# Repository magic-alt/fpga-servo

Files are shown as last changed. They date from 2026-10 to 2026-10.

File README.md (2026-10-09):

# fpga-servo

FPGA-based servo drive development platform for the ALINX AX7010 / Zynq-7000 board.

## Rev.A hardware target

`hardware/ax7010_servo_reva` is the first KiCad hardware baseline for a single-axis PMSM/BLDC servo inverter:

- 24-48 V DC bus, 10 A continuous phase current, 20 kHz PWM (confirmed 2026-10-09)
- three-phase bridge using 100 V N-channel MOSFETs
- FD6288T three-phase half-bridge gate driver
- three inline 5 mOhm phase shunts
- INA241A2 current-sense amplifiers, 20 V/V, 5 V supply, mid-supply reference
- ADS8588S 8-channel simultaneous 16-bit SAR ADC
- differential ABZ encoder input using AM26LV32E
- AX7010 40-pin PL expansion connector interface
- 2-layer PCB baseline, 2 oz copper recommended

The official recent AX7010 documentation names the two 40-pin PL expansion connectors J10/J11. Some older board revisions/silkscreens may differ; therefore the design uses neutral names `AX7010_PL_A` / `AX7010_PL_B` and documents the electrical pin map explicitly.

## Repository layout

- `hardware/` KiCad 10-native schematic / PCB baseline, BOM and design notes
- `fpga/` AX7010 XDC pin constraints matching the hardware pin map
- `docs/` architecture, calculations, bring-up and release gates
- `tools/` lightweight repository checks that do not require KiCad to be installed

## Status

Rev.A is a **development baseline**, not a fabrication release. Critical architecture, power-stage topology, interface allocation, footprint intent and layout zoning are present. Before fabrication the release gates in `docs/release_gates.md` must be closed, especially KiCad ERC/DRC, exact footprint verification, switching-loop review, thermal verification and connector revision confirmation.

Latest [layout-entry repair](docs/layout_entry_repair_2026-10-09.md): bootstrap diode polarity and ADC serial-mode straps are corrected; ERC and schematic/PCB parity are clean. PCB still has 271 DRC violations and 478 unconnected items; placement/routing freeze remains blocked. The [earlier schematic explanation and audit](docs/schematic_layout_entry_review_2026-10-09.md) retains passive simulation and remaining electrical/bench gates.

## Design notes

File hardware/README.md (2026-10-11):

# AX7010 Servo Drive Rev.A - KiCad baseline

**Current delivery scope (user revision, 2026-10-10): BOM and schematic only. PCB/layout repair is deferred. The working PCB retains earlier development edits and is not synchronized to the final bus-OCP schematic; the isolated unfinished routing candidate is not adopted. Do not use this board for fabrication or reuse historical zero-DRC/parity claims for the current schematic.**

## Files

- `ax7010_servo_reva.kicad_sch` - KiCad 10-native top-level schematic
- `power_input.kicad_sch`, `aux_power.kicad_sch`, `gate_inverter.kicad_sch`, `current_adc.kicad_sch`, `encoder.kicad_sch`, `ax7010_interface.kicad_sch`, `ocp_latch.kicad_sch` - native hierarchical child sheets
- `ax7010_servo_reva.kicad_sym` - versioned KiCad 10-native project symbol library
- `ax7010_servo_reva.kicad_pcb` - 2-layer PCB placement / critical-routing baseline
- `ax7010_servo_reva.kicad_pro` - KiCad project settings
- `bom.csv` - first-pass BOM and sourcing gates

`fp-lib-table` resolves `fpga-servo.pretty` through `${KIPRJMOD}`. `sym-lib-table` is versioned and resolves the project library through `${KIPRJMOD}`. The project therefore opens and passes ERC without a machine-specific global symbol table. `*.kicad_prl` and lock files remain local state.

The 2026-10-09 review fixed stale hierarchy instance roots, added seven FPGA-input pull-downs and six local IC bypass capacitors, repaired C43/C44/C45 (previously both terminals on GND), and synchronized the BOM and actual DNP flags. See `docs/schematic_review_2026-10-09.md` for evidence and remaining layout gates.

## Layout partitioning

From left to right in the PCB file:

1. AX7010 PL headers and signal interface
2. ADC + analog acquisition
3. gate driver / safety logic
4. six-MOSFET bridge + current shunts
5. motor and DC-bus terminal blocks

The auxiliary buck supply is kept along the top edge, away from the current-sense/ADC area.

## Current selection implementation (2026-10-10)

The eight-page native hierarchy retains three phase-inline INA240A1DR channels and 5 mΩ / 3 W two-terminal SMD shunts. Unused J2 is removed. Bus-only positive OCP uses a fourth INA240A1DR, a 2 mΩ / 3 W shunt and one LM393LV comparator at nominal +25 A. U16 and phase-window divider parts are removed. The hardware ARM latch and supervised clear remain.

The gate driver is non-inverting DRV8300DPWR with internal bootstrap diodes, 470 nF bootstrap capacitors and initial 33 Ω gate resistors. F1 is onboard Littelfuse 0456025.ER; no external fuse holder is required. J3.1 is VIN_RAW and F1 feeds VIN_FUSED. J6 remains an off-board PSU reference.

Important land decisions:

- RSH1..RSH4: local HoYLR2512_Kelvin two-terminal land; independent inner-side sense routing is required on all eight inputs.
- J4: KEFA KF950-9.5-3P; J1/J5: JILN 3210 family, finished holes 1.02 ±0.03 mm.
- L1: SOREDE 68 µH prototype selection; full 1 A regulator operation and inductor thermal rating remain unqualified. L2: Sunlord SWPA4020S2R2MT.
- NTC1/2: Shiheng CMFA103F3950 on a shared reviewed 0603 land. The onboard NTC2 does not establish actual remote motor temperature.

The [selection record](../docs/lcsc_sourcing_review_2026-10-10.md) and current native verification evidence supersede previous component counts and selection snapshots. BOM and procurement candidates are generated from the current hierarchy and sourcing evidence; stock observations are not reservations.

## Acceptance and limits

Run all repository checks, native ERC, fresh physical-pin netlist checks, all-severity PCB DRC with schematic parity, and the eight-branch Kelvin audit. Review every exported schematic page. A zero count does not establish electrical or thermal qualification.

See [release gates](../docs/release_gates.md). Gate A/B remain blocked pending measured switching, OCP delay/SOA, supply sequencing, current/thermal, connector and regeneration qualification. No fabrication approval is implied. Older implementation reports remain historical evidence; their external fuse, INA241, FD6288 and phase-window OCP descriptions do not describe this revision.

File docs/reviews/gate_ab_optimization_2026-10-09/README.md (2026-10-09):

# Gate A/B 验证流程优化 — 2026-10-09

基于远端 `feat/gate-ab-electrical-verification-20261009` 的 `389fbb5`；被测实现提交 `80512b5`。优化分支 `fix/gate-ab-evidence-integrity-20261009`。未修改硬件、FPGA、BOM 或库；原 main 工作区未提交配置和 history 保留。

## 修复与复核

- 清除预期波形后才执行模拟器；旧波形 + 空操作程序不再 PASS。
- 拒绝损坏、非有限值、时间倒序和覆盖不完整的波形。
- 缺失输入、畸形 XML、模拟器失败均输出 FAILED，覆盖旧资格 JSON。
- 网表脚本 ERC 明确 NOT_RUN；统一入口原生 ERC 报告才构成 ERC 证据，校验 metadata、完整层次 UUID、显式 violations 数组。
- 每次创建独立运行目录，保存源码前后哈希、产物哈希、工具版本、Git SHA/工作区状态、各步退出码和日志；CI 复用入口。
- 独立代码审查指出的畸形 XML/不完整 ERC 报告问题，均先通过 CLI 回归复现后修复，并通过复审。

## 本机新执行结果

macOS、Python 3.12.15、KiCad 10.0.3、ngspice 47。

| 验证 | 新结果 |
|---|---|
| 六项仓库检查 | 全部 PASS |
| 原生 ERC | 0 错误 / 0 警告 / 0 排除；4 类继承 ignored checks 如实保留，未改变规则 |
| 新原生板级网表 | 157 元件 / 166 网络 |
| 安全连接、PCB parity、PCB constraints | PASS |
| OCP 稳态数字回归 | 531 场景 PASS；不代表模拟链路响应验证 |
| Gate A/B 回归 | 18 项 PASS，无跳过；包含新鲜网表 mutation 和真实 ngspice |
| 入口失败隔离回归 | 2 项 PASS |
| PCB / 教程审计回归 | 11 / 4 项 PASS |
| 理想被动模型 | 回馈电容规律与 OCP RC 门限越过互检 PASS；无主动器件模型资格声明 |
| 源码哈希 | 各次运行前后精确一致 |
| 普通入口 | 自动证据 PASS，退出 0（提交前同一实现执行） |
| `--strict-gates` | 自动证据 PASS，Gate A/B BLOCKED，退出 2 |
| `--with-drc` | FAILED，退出 1；DRC 进程退出 -5，没有新 DRC 报告 |

DRC 日志：`Swift/SwiftNativeNSArray.swift:78: Fatal error: Array index out of range`。带 parity/refill 与最简原生命令均复现；根因尚未确定。未安装/升级工具或更改全局配置进行规避，未用历史 271/478 计数替代新执行结果。制造状态保持未放行。

## 证据

- [严格门禁 manifest](strict/manifest.json)、[本次 ERC](strict/erc.json)、[资格计算](strict/qualification.json)
- [Gate A/B 回归日志](strict/gate_ab_regressions.log)、[PCB 回归](strict/pcb_regressions.log)、[教程回归](strict/tutorial_regressions.log)
- [DRC 失败 manifest](drc/manifest.json)、[原生崩溃日志](drc/drc.log)

此目录保存精选原始报告，manifest 中保留完整运行全部产物的哈希。完整原始运行（含新导出网表与 SPICE 波形）分别位于隔离工作区的 `artifacts/gate-ab/20261009T153147Z-ys3wvk8b` 与 `artifacts/gate-ab/20261009T153206Z-k4xtcjo3`；可用 `python3.12 tools/run_gate_ab.py` 重新生成独立证据。入口失败隔离回归另用 `python3.12 -m unittest discover -s tools -p test_run_gate_ab.py -v` 执行。

Gate A/B 工程门禁仍 BLOCKED；主动器件动态模型、ADC 欠压许可、回馈策略、总关断时间及台架实测等清单见 [资格说明](../../gate_ab_verification_2026-10-09.md) 和 [release gates](../../release_gates.md)。远端 CI 尚未运行本地优化提交。

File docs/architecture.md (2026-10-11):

# Rev.A architecture

## Design intent

This board is a lab/engineering servo-drive daughter board for the ALINX AX7010. It deliberately keeps the hard real-time PWM, ADC timing and encoder counting in the Zynq PL while leaving high-power switching, signal conditioning and encoder line reception on the daughter board.

## Electrical target

| Item | Rev.A target |
|---|---:|
| DC bus | 24-48 V (confirmed 2026-10-09) |
| Operating bus maximum | 48 V; transient clamp/energy limit pending |
| MOSFET VDS | 100 V |
| PWM | 20 kHz |
| Continuous phase current | 10 A RMS (confirmed 2026-10-10) |
| Peak phase current | 20 A for 30 s (confirmed 2026-10-10); repetition interval pending |
| Maximum ambient | 40 degC (confirmed 2026-10-10) |
| Temperature-rise target | <=50 K; measurement locations pending; does not override lower component qualification limits |
| Cooling | Forced air (confirmed 2026-10-10); airflow and fan-fault behavior pending |
| Phase-current shunts | 5 mOhm, 3 W two-terminal SMD, independent Kelvin pickup; mounted thermal qualification open |
| Bus OCP shunt | 2 mOhm, independent Kelvin pickup; nominal positive +25 A trip only |
| Current gain | 20 V/V |
| Current transfer | 0.1 V/A |
| Current output zero | VA_5V / 2; nominal 2.55 V, requires per-channel calibration |
| ADC | 8 ch, simultaneous, 16 bit, 200 kSPS/ch |
| Encoder | 5 V ABZ (confirmed 2026-10-10); existing differential A+/A-, B+/B-, Z+/Z- interface; current/startup/common-mode envelope pending |
| Logic | 3.3 V |
| PCB | 2 layer, 1.6 mm, 2 oz recommended |

The latest user instruction removes the brake circuit from scope (2026-10-10). No board brake is added and PSU regeneration absorption is not assumed. S03 system surge/regeneration qualification remains OPEN; brake sizing is not a prerequisite for the other repair work. See the [thermal and encoder design brief](brake_thermal_design_basis_2026-10-10.md). The 20 A operating peak is distinct from the hardware OCP threshold and its fault overshoot; it is not yet demonstrated as an absolute current ceiling. U26 local free-air temperature must remain <=85 degC to use the current maximum-delay budget; 40 degC ambient permits only 45 K local rise there, pending thermal proof or a qualified redesign.

## Functional blocks

1. **DC-link / protection**
   - onboard F1: Littelfuse 0456025.ER, 25 A SMD, 72 VDC / 500 A interrupt rating; J3.1 enters VIN_RAW, F1 feeds VIN_FUSED; J6 alone is an excluded external system interface. No external fuse/holder
   - confirm actual bus current/inrush, source fault current <=500 A, bus surge/regeneration <=72 V, cable energy and fuse thermal coordination before higher-power operation
   - bulk capacitance close to bridge; D1 TVS is DNP, so no fitted TVS protection or qualified regeneration sink
   - bus-voltage divider to ADC

2. **Three-phase inverter**
   - six BSC040N10NS5 100 V MOSFETs
   - DRV8300DPWR non-inverted TSSOP20 driver; DI variant is not interchangeable
   - per-gate series resistor and gate-source pulldown
   - integrated bootstrap diodes; 470 nF CBOOT per high-side channel; external D2..D4 removed

3. **Phase-current measurement**
   - one 5 mOhm two-terminal SMD shunt in each motor phase
   - INA240A1 high-side/bidirectional amplifier per phase
   - REF1=VA_5V, REF2=GND -> nominal 2.55 V zero-current output
   - Kelvin sense traces, no load current in sense copper

4. **Data acquisition**
   - ADS8588S, 8 simultaneous channels
   - CH1/2/3: IU/IV/IW
   - CH4: VBUS
   - CH5: MOSFET-board NTC
   - CH6: board-mounted NTC2 (legacy net name NTC_MOTOR); no external motor sensor interface exists. S12 remains OPEN until the required sensing location/interface is confirmed.
   - CH7/8: unused, currently tied to GND
   - serial interface uses two DOUT lines; J2 is removed; only J1 connects the active AX7010 J10 signals
   - serial-mode DB0..6, DB9..13 and DB14/HBEN now visibly grounded; U6 uses the dedicated ADS8588S_SERIAL symbol

5. **Encoder**
   - AM26LV32E quad RS-422 receiver at 3.3 V
   - 120 ohm termination footprints on A/B/Z are currently DNP; fit decision depends on actual cable/encoder
   - shared VA_5V encoder supply through F2 PTC; exact PTC and short-circuit isolation remain unqualified

6. **Auxiliary power**
   - LM5164: DC bus -> 12 V gate/aux rail
   - TPS62901RPJR external-feedback 12 V -> nominal 5.1 V VA_5V rail; R94=75k/R95=10k, MODE=VIN (forced PWM 2.5MHz), VOS=output
   - 3.3 V logic is supplied by AX7010 VIO; there is no local 3.3 V LDO in the current schematic
   - safety AND gates and encoder receiver run from AX7010 `VIO_3V3`; ADC DVDD also uses this rail
   - dedicated digital isolation/buffer arrays are not fitted; partial-power behavior remains a qualification gate

## Safety state

All six non-inverted DRV8300DPWR PWM inputs are hardware-gated before the driver. `RUN_OK = GATE_EN & PWR_READY & ARMED`; any missing condition forces all six driver input commands low. FPGA deadtime remains at least 500 ns, with switching and shoot-through verification still required. CBOOT1..3=470 nF connect BST to each switch node; the driver has integrated bootstrap diodes. RG1..6=33 ohm and gate-source pulldowns=10 kohm require measured waveform validation.

The latest authorized hardware OCP detects **positive bus current only**, independently of the phase ADC. RSH4=2 mOhm separates VBUS_PROT from VBUS_BRIDGE, which supplies the high-side MOSFET drains. U5 INA240A1DR senses upstream minus downstream with both reference pins grounded, producing ideal 0.04 V/A for positive current. U15 LM393LVDDFR compares this output at pin 2 against R50=8.2k/R53=2k threshold at pin 3. At VA5=5.1 V, 1.0 V threshold gives nominal +25 A trip and pulls OCP_N low above threshold. U16/R51/R52 are removed. Reverse-current and phase-current window OCP are not provided.

The fresh passive calculation gives +24.357135..+25.659766 A using regulated VA5 bounds, divider +/-0.1% and shunt +/-1%. Adding selected-part TCR and published INA/comparator error terms expands the conditional static engineering estimate to +23.935464..+26.107636 A for +25..+125 degC component temperature and 24..48 V DC common-mode. This is not a permitted operating-temperature range or a guaranteed trip interval: supply test-condition applicability, grounded-reference errors, assembly/aging drift and dynamic effects remain open. See [the error budget and OEM limits](design_calculations.md). Bus current is not phase current, so this threshold is not an absolute ceiling for the 20 A phase operating peak. The FPGA diagnostic path remains available but does not replace hardware OCP.

Phase INA240A1 U2..U4 retain REF1=VA_5V and REF2=GND, nominal 2.55 V zero and 0.1 V/A sensitivity; R40..R42/C40..C42 serve the ADC only, with no OCP taps. ADS8588S straps remain `OS=000`, `PAR/SER=1`, `STBY=1`, `RANGE=0` (bipolar 5 V), `REFSEL=1`, and `DB15/BYTE_SEL=0`. Each phase and bus shunt's sense traces must reach the inner terminal lands independently of force copper.

## Grounding strategy

The PCB uses one continuous ground reference on the bottom layer. High-current bridge return paths stay local to the DC-link negative node and do not share narrow traces with ADC/encoder return currents. The analog section is physically isolated from switch nodes rather than separated with a slit plane.

## Configuration-time default and restart policy

R80..R85 pull the six raw PWM inputs to GND through 10k. R86 pulls GATE_EN to GND through 10k. With VIO valid and FPGA outputs high impedance, the AND gates have defined low commands and RUN_OK remains low. R56..R61 are separate pull-downs on the already gated driver inputs. C80..C83 bypass the four safety logic supplies; C84 bypasses bus INA240 U5 and C85 bypasses LM393LV U15. C43..C45 bypass INA240 supply pins to GND.

U20 implements hardware ARM latching, with supervised VIO/VA5 reset and raw OCP/PWR_GOOD asynchronous clear. Fault recovery alone cannot resume PWM. J1.10 FAULT_CLEAR re-arms on a rising edge with GATE_EN low. See `ocp_latch_review_2026-10-09.md` for the required clear protocol, timing conditions and bench gates. The bus detector has a nominal 1.000 V threshold (+25 A positive bus current). Response time, fault overshoot and complete error budget remain open.

U26 SN74LVC3G17 applies Schmitt conditioning to the open-drain supervisor reset, raw OCP_N and raw PWR_GOOD before ordinary CMOS logic. The conditioned PWR_READY feeds U11/U23; raw diagnostic nets and their original pull-ups remain intact.

U25 is now TPS389001DSER, independently powered by VIO and sensing VA5 through R92=3.24k/R93=1k. Undervoltage asynchronously clears ARM; recovery alone cannot re-arm. See [2026-10-10 repair](adc_undervoltage_repair_2026-10-10.md) for physical pin maps, static margins and open dynamic qualification. R92 uses the reviewed +/-0.702% static budget; the minimum falling threshold is 4.791889 V, maximum recovery 5.001931 V, and static VA5 range 5.026621..5.173923 V. These values do not qualify rapid droop or gate-off latency. ADC current-zero calibration and encoder supply acceptance must use the 5.1 V nominal rail.

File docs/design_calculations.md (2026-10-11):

# Rev.A design calculations

Current confirmed baseline: **24-48 V, 10 A RMS continuous phase current, 20 kHz PWM; 20 A peak for 30 s; 40 degC maximum ambient; <=50 K temperature rise; forced-air cooling; 5 V ABZ encoder; brake circuit cancelled by latest user instruction; PSU absorption not assumed** (2026-10-10). Peak repetition interval, airflow/fan failure, encoder maximum/startup current remain pending. See [thermal and encoder design basis](brake_thermal_design_basis_2026-10-10.md) and [current qualification record](layout_followup_qualification_2026-10-10.md); these inputs do not close release gates.

## Current sensing

For each phase:

- `Rshunt = 5 mOhm`
- `Gain = 20 V/V`
- `Vout_delta = Iphase * Rshunt * Gain`

Therefore:

`Vout_delta = Iphase * 0.005 * 20 = 0.1 * Iphase [V]`

With VA5=5.1 V nominal and reference=VA5/2=2.55 V:

| Phase current | Amplifier output |
|---:|---:|
| -20 A | ~0.55 V |
| -15 A | ~1.05 V |
| -10 A | ~1.55 V |
| 0 A | ~2.55 V |
| +10 A | ~3.55 V |
| +15 A | ~4.05 V |
| +20 A | ~4.55 V |

Software phase-current limits require calibration and dynamic validation. The approved phase peak is 20 A for 30 s. The latest authorized hardware OCP is a separate **positive bus-current** detector with nominal +25 A trip; U2..U4 remain phase ADC measurement channels and have no OCP comparator taps. Bus current and phase current are different quantities, so the difference between 20 A phase peak and 25 A bus trip is not a no-nuisance-trip margin.

RSH4=2 mOhm lies between `VBUS_PROT` (terminal 1, U5.IN+ pin 8) and `VBUS_BRIDGE` (terminal 2, U5.IN- pin 1). U5 is INA240A1DR, gain 20 V/V, with both reference pins grounded. Its ideal positive transfer is `Vout = Ibus * 0.002 * 20 = 0.04 * Ibus`. R50=8.2k from VA5 and R53=2k to GND set `Vthreshold = VA5 * 2/10.2`, giving 1.000 V at VA5=5.1 V and `Itrip=1/0.04=25 A`. U15 LM393LVDDFR compares U5.OUT at IN- pin 2 with threshold at IN+ pin 3; positive overcurrent pulls OCP_N low. U15's unused comparator has IN+ pin 5 at GND, IN- pin 6 at threshold, and output pin 7 NC. U16/R51/R52 are removed. This circuit provides **no reverse-current OCP** and no phase-current window protection.

The fresh candidate XML (2026-10-10), `check_adc_validity.py` and `corner_current_limits()` give VA5=5.026621..5.173923 V. Combining this rail range, R50/R53 initial tolerance +/-0.1%, and RSH4 +/-1% yields **positive passive-only trip +24.357135..+25.659766 A**. This excludes divider/shunt temperature and lifetime drift, INA gain/offset/output swing and PWM common-mode recovery, LM393LV offset/overdrive/propagation, ripple, pull-up/logic/gate delay and fault-current overshoot. It is not a guaranteed trip interval or maximum fault current. The grounded-reference INA output near zero and negative current also requires bench characterization; no negative-current transfer or protection is claimed.

The [versioned static-budget evidence](sourcing/bus_ocp_static_budget_2026-10-10.json) records the native XML hash, OEM sources and limits. The extended static engineering budget in `bus_static_error_budget()` gives **+23.935464..+26.107636 A**, while preserving nominal +25 A. Its conditional calculation envelope is local component temperatures +25..+125 degC and DC bus common-mode 24..48 V; this is not permission to exceed the board's 90 degC hotspot target or another component's lower limit. The shunt OEM only specifies its TCR test over +25..+125 degC, so no cold-temperature bound is claimed.

| Term | Maximum/allocated magnitude used |
|---|---:|
| R50 PTFR0603B8K20P9 | Initial 0.1% + 25 ppm/degC × 105 K = 0.3625% |
| R53 TD03G2001BT | Initial 0.1% + 25 ppm/degC × 105 K = 0.3625% |
| RSH4 HoYLR2512-3W-2mR-1% | Initial 1% + 50 ppm/degC × 100 K = 1.5% |
| INA240 gain | 0.2% + 2.5 ppm/degC × 100 K = 0.225% |
| INA240 input offset | 25 uV + 250 nV/degC × 100 K, plus DC CMRR and PSRR = 87.739 uV |
| LM393LV input offset | Full-temperature 3 mV, plus DC CMRR and PSRR = 4.155 mV |

The [RESI PTFR ordering table](https://atta.szlcsc.com/upload/public/pdf/source/20250401/FF0B2EF5B31106388F28E532ECCD4B84.pdf) identifies code P as 25 ppm/degC; the [FH TD ordering table](https://atta.szlcsc.com/upload/public/pdf/source/20200616/C657321_2CFA27FA726BC0D0F6223AF922169515.pdf) identifies G as 25 ppm/degC. A conservative 105 K resistor span covers a +20 degC reference to +125 degC. [HoYLR's exact 2mOhm approval sheet](https://atta.szlcsc.com/upload/public/pdf/source/20260807/2744A3B9486B05923CE3C700940B3DAC.pdf) specifies 50 ppm/degC. These initial-plus-TCR bounds do not include mounting or qualification-test drift.

The [INA240 electrical table](https://www.ti.com/lit/ds/symlink/ina240.pdf) supplies gain/offset limits and drift, minimum DC CMRR 120 dB and maximum PSRR 10 uV/V. The model allows common-mode change from the 12 V test point to 48 V and actual supply deviation from 5 V. The [LM393LV table](https://www.ti.com/lit/ds/symlink/lm393lv.pdf) supplies full-temperature +/-3 mV offset, 60 dB CMRR and 70 dB PSRR; drift is not added again. A 1.1 V comparator common-mode envelope bounds the threshold crossing.

The equation is `Itrip = ((Vthreshold + VOS_comparator) / G_actual - VOS_INA) / Rshunt_actual`, sweeping independent worst signs and both verified VA5 bounds. This remains **an engineering estimate, not a guaranteed trip interval**: LM393LV's quoted error-table conditions are at/up to 5 V, while actual VA5 is slightly higher; INA reference rejection and input-bias mismatch lack guaranteed maxima for this application. Grounded-reference transfer, Kelvin/thermoelectric errors, reflow, load-life/humidity drift, PWM transients and dynamic fault overshoot still need qualification. The OEM shunt's separate reliability-test allowances cannot be treated as zero drift or collapsed into a lifetime guarantee. The model checks the three exact MPNs before using their TCRs; an alternate needs its own reviewed budget.

RSH4 dissipates 1.25 W at a constant 25 A and 0.8 W at a constant 20 A. Its bus RMS current, pulse energy, mounted temperature and independent inner-land Kelvin pickups require separate qualification; phase RMS current cannot be substituted for bus RMS current.

Shunt dissipation is `P = I_RMS^2 * R`:

| RMS current | Shunt dissipation |
|---:|---:|
| 10 A | 0.50 W |
| 15 A | 1.125 W |
| 20 A | 2.00 W |
| 25 A | 3.125 W |

Select HoYLR2512-3W-5mR-1% (3 W, two-terminal SMD). Apply independent inner-land Kelvin pickup and verify its derating and assembled temperature. A 3920 >=5 W alternative is the fallback if the 2512 assembly cannot meet the thermal limit.

At the confirmed 10 A RMS, each nominal shunt dissipates 0.5 W. A phase held at the 20 A magnitude bound dissipates 2 W; for 30 s this is 60 J per shunt, before resistance tolerance and temperature drift. A sinusoidal phase with 20 A instantaneous amplitude has a different RMS loss; use the 2 W value as a conservative per-shunt upper envelope until the actual peak waveform is specified. With baseline 10 A RMS and a conservative 20 A flat-current interval occupying fraction d, the illustrative average is `Pshunt=0.5+1.5d W`; for a start-to-start repetition period Trep, `d=30/Trep` with Trep>=30 s. No repetition period is assumed.

At 40 degC ambient, the general 50 K rise target corresponds to a 90 degC measured hotspot limit, subject to every component's lower qualified limit. A 50 K rise implies an effective shunt-to-ambient thermal resistance <=100 K/W at steady 0.5 W, or <=25 K/W at steady 2 W; these are assembly targets, not package ratings. For a first 30 s pulse from an established 10 A RMS thermal state, an illustrative linear thermal model requires `0.5*Rtheta_steady + 1.5*Ztheta(30s) <=50 K`; repeated pulses require accumulation, hot resistance and airflow validation. The shunt's nominal 3 W rating does not prove this condition. U26's current maximum-delay qualification is limited to 85 degC local free-air temperature, hence <=45 K local rise at the confirmed ambient. Forced air requires minimum airflow, blockage/fan-loss handling and assembled-board soak evidence.

## ADC resolution

The ADS8588S is configured for ±5 V input range. The nominal LSB is:

`10 V / 65536 = 152.6 uV/LSB`

Since current sensitivity is `0.1 V/A`, the ideal code resolution is:

`152.6 uV / 0.1 V/A = 1.526 mA/LSB`

Noise, PWM common-mode transients, reference error and layout dominate before quantization does.

## Bus-voltage divider

Rev.A nominal divider:

- high side: 280 k + 280 k
- low side: 39 k
- total: 599 k

`Vadc = Vbus * 39 / 599 = 0.065108 * Vbus`

| VBUS | ADC voltage |
|---:|---:|
| 24 V | 1.563 V |
| 48 V | 3.125 V |
| 55 V | 3.581 V |
| 60 V | 3.906 V |
| 75 V | 4.883 V |

The board is not specified for 75 V continuous operation; this table only shows divider headroom.

The operating range is 24-48 V; every table row above 48 V is calculation-only. C5=10nF and `(560k || 39k)` give tau=364.608us and fc=436.51Hz. This bus-monitor filter cannot be treated as fast hardware overvoltage protection.

## MOSFET conduction sanity check

For one current path through two BSC040N10NS5 devices, using 4 mOhm each at the datasheet test condition:

`Ppath ~= I^2 * 8 mOhm`

- 10 A -> 0.8 W instantaneous conduction path loss
- 15 A -> 1.8 W (historical comparison)
- 20 A -> 3.2 W
- 25 A -> 5.0 W

Actual inverter dissipation must be computed over PWM duty, device temperature, switching energy and dead-time diode conduction. These values are only a first-order check.

## Gate-drive current sanity check

U1 is the non-inverted **DRV8300DPWR**, with integrated bootstrap diodes. The DI variant is not interchangeable with the hardware all-low inhibit. D2..D4 are removed; CBOOT1..3 are 470 nF between BST and the corresponding switch node, and RG1..6 are 33 ohm. See the [TI DRV8300 datasheet](https://www.ti.com/lit/ds/symlink/drv8300.pdf) for the D/DI input distinction and PW20 pin map. All six input commands are gated; FPGA deadtime remains at least 500 ns, pending measured switching verification.

Using BSC040N10NS5 Qg=72 nC as an illustrative charge and the driver's typical 0.75 A source/1.5 A sink capabilities gives Q/I=96 ns/48 ns. These are ratios, not guaranteed switching or fault turn-off times: 33 ohm resistance, Miller charge, gate voltage, driver impedance and board inductance dominate actual waveforms. One 72 nC charge from a nominal 470 nF bootstrap capacitor gives an ideal 0.153 V droop before effective-capacitance derating, quiescent/leakage charge, duty-cycle hold time and recharge losses. Bootstrap refresh, UVLO, effective capacitance and full shutdown latency remain unqualified.

## Onboard input fuse

F1 is **Littelfuse 0456025.ER**, a 25 A very-fast-acting SMD fuse on the PCB. J3.1 and F1.1 are VIN_RAW; F1.2, Q7 drain and the U18 LM74502 reverse-polarity controller input are VIN_FUSED. The LM5164 auxiliary regulator is supplied from VBUS_PROT, downstream of reverse-polarity protection. J6 is only the excluded external system interface; no external fuse or holder is required by this design revision.

The [Littelfuse 456 datasheet](https://www.littelfuse.com/assetdocs/littelfuse_fuse_456_datasheet.pdf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) specifies the **25 A row** at 500 A interrupting capacity at 72 VDC, and 1000 A at 32 VDC. Its 125 VAC label does not establish a 125 VDC rating. The 72 VDC rating exceeds the 48 V operating maximum; regeneration/surge bus voltage <=72 V and prospective source fault current <=500 A remain open qualification requirements for this prototype selection. Catalog stock is not electrical qualification.

Nominal cold resistance is 1.92 mOhm and nominal melting I²t is 45 A²s; neither alone proves fault coordination. Manufacturer time-current, continuous-current/ambient derating, inrush, source/cable energy and mounted-temperature limits must be met. OEM thermal conditions use broad 100 um copper; the present two-layer copper/via implementation does not independently prove 25 A operation. F1 does not replace fast bus OCP or limit fault current to 25 A. This is a documented critical single-source prototype exception.

## VA5 validity and R92 tolerance

U25 TPS389001DSER senses VA5 through R92=3.24k/R93=1k while powered independently by VIO. R92's selected 0.1%, 25 ppm/C primary and reviewed alternative use a common +/-0.702% static budget; R93/R94/R95 use +/-0.25% including their stated allocations. These are prototype budgets derived from separate qualification tests/allocations, not a combined-environment or lifetime guarantee.

`check_adc_validity.py` calculates falling shutdown threshold 4.791889..4.961002 V, maximum recovery 5.001931 V, and regulated VA5 5.026621..5.173923 V. The minimum falling threshold is 41.889 mV above ADS8588S's 4.75 V minimum. The allocated 10 mV normal ripple still leaves static recovery headroom. This does not qualify fast droop: TPS3890's 18 us typical delay at 5% overdrive is not a guaranteed maximum, and the complete supervisor-to-MOSFET shutdown chain remains open.

## Two-layer current routing

The high-current path must not rely on a single narrow trace. Plan wide top-layer copper, bottom reinforcement and qualified stitching near terminals/MOSFETs/shunts. The prior routed PCB is a development baseline; SMD-shunt integration requires fresh routing, DRC and thermal review. Verify temperature rise on the actual stack-up and copper weight.

## Local passive simulation (2026-10-10)

`tools/simulate_layout_entry.py` extracts actual passive values and checks their physical-pin topology in a fresh KiCad XML netlist before emitting six ngspice decks, CSV waveforms, JSON results and a plot. This is not a complete inverter/device simulation.

- R40/C40: tau=47ns, fc=3.386MHz; 20kHz attenuation is only -0.0001515dB. The filter does not remove PWM ripple and serves only the phase ADC. Its ideal 2.5-to-4.9 V step crosses the 3.7 V midpoint at about 1.03358 us for a step beginning at 1.001 us; this is phase ADC settling, not bus OCP delay.
- R88/C92: tau=1us with an ideal FPGA output. No Schmitt threshold, propagation, metastability or power-ramp model is included.
- C1+C2=200uF nominal: an unsunk ideal 1A regeneration current raises 48V to 55V in 1.4ms, storing only 0.0721J extra. 55V is an overvoltage example, not an operating allowance.
- Three 5mOhm shunts at 10A RMS dissipate 0.5W each, 1.5W total. Package rating alone does not qualify assembly temperature.

Full current/thermal/switching qualification remains open; see [power-stage review](power_stage_layout_review_2026-10-09.md) and [analog/safety review](analog_safety_layout_review_2026-10-09.md).

## Kelvin electrical-node modeling

The selected two-terminal SMD shunt has one physical terminal per side. Independent sense and force traces meet within that terminal land and share its electrical node:

- U phase: `SW_U` and `PH_U`
- V phase: `SW_V` and `PH_V`
- W phase: `SW_W` and `PH_W`
- Bus: `VBUS_PROT` and `VBUS_BRIDGE`

Kelvin behavior is enforced in PCB routing: each INA240 input trace must originate independently at the inner edge of the corresponding two-terminal SMD shunt pad. Force and sense copper may meet only within that terminal land. A two-terminal shunt must not be represented by invented physical sense pins or jumper groups. PCB integration and thermal qualification are separate gates.

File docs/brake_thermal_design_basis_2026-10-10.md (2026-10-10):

# 20A / 30秒、40°C风冷与编码器供电设计依据

## 当前确定的输入

用户确认：24..48V母线、20kHz PWM、10Arms连续相电流、20A峰值持续30秒、最高环境40°C、允许温升50K、风冷、5V ABZ编码器；用户最新指令取消制动电路；不将板载制动列为待实现任务，不假定电源具有回馈吸收能力。20A重复周期尚未给出，不采用历史25A/5秒。不得把20A相电流转换为20A母线回馈电流。

本文件保留热设计和编码器供电候选依据。制动候选方案已按用户最新指令撤销。当前原理图没有制动支路；D1仍DNP，U18 OV仍接地。S03/S05/S08/S11和动态资格仍OPEN。

## 热设计与布局限制

10Arms时，每只5mΩ分流器名义0.5W；20A幅值持续30秒的保守平顶包络为2W和60J/只。三只各自使用该上界有利于保守热设计，并不意味着平衡三相能同时以同向20A运行。实际波形、峰值重复周期及热阻抗决定真实损耗和热累积。

从10Arms热稳态切换到上述峰值包络，线性近似为`ΔT(30s)=0.5Rθ+1.5Zθ(30s)`；要求测量点不超过50K温升，需计入热态阻值、器件/铜/端子互热与风量。重复周期T从一次峰值开始到下一次开始计算，`d=30/T`，名义平均每只分流器`P=0.5+1.5d W`；未知T时不得给出平均损耗合格结论。

40°C+50K得到一般测量点90°C限值，但不能套用到具有更低资格温度的部件，也不能把外壳/板温当结温。U26 SN74LVC3G17 Rev.F §6.6最大延时表只覆盖TA=-40..85°C；该芯片推荐工作温度到125°C并不扩大延时表。沿用原32ns数字链预算时，应把U26放在远离MOSFET、分流器和磁件的冷区，证明局部自由空气温度<=85°C（40°C环境下局部温升<=45K），并满足输出负载条件。若不能保证，则需要替换有相应高温最大时序保证的逻辑并重新建立延时预算，不按典型曲线外推。

风冷验收需要最小风量/流向、堵塞及风扇故障处理；PCB散热铜、风道、外壳和安装状态必须与热试验一致。30秒是长脉冲，不能只用MOSFET纳秒/微秒SOA图或分流器5W名义额定放行。

## 5V ABZ默认兼容合同候选

现有接口是差分RS-422 A+/A−、B+/B−、Z+/Z−，不是所有“ABZ”电气输出都通用。建议默认限定为允许4.5..5.5V供电的5V差分型号，预留**300mA连续供电设计额度**；这是一项待电源和短路资格验证的工程预算，不是工业ABZ统一额定或现板已保证的输出能力。

例：SICK VFS60系列官方2013年产品资料的4.5..5.5V TTL/RS422档列出无负载工作电流40mA、输出负载电流30mA；按`40mA+3×30mA=130mA`可作量级叠加参考。该历史系列资料不能替代当前准确采购型号的最大输入电流保证，也不代表用户已选定该编码器。300mA设计额度不涵盖未知上电浪涌、线缆充电及所有其他型号。最终选用型号必须满足明确的持续/启动电流、供电窗口、共模和频率合同。

当前VA5静态5.026621..5.173923V符合上述候选编码器窗口的电源端范围，但F2、线缆、连接器压降和动态下陷未计入。仅静态在300mA下，从最低VA5到4.5V可分配总串联电阻约1.755Ω；此数值未留瞬态/纹波裕量，不能直接作为布线允许值。F2的0.5A文字不是热态保持电流保证，PTC也不是快速精密限流器。

编码器当前与ADC/OCP共用VA5。需比较两种方案：带反灌/短路资格的限流支路，或由12V产生独立编码器5V再限流。独立支路降低直接拖垮VA5的耦合，但12V总负载和启动仍需核算。未确定负载/启动与器件之前，不将F2占位符视为已修复，也不任意添加一个普通PTC关闭S08/S11。

## 制动范围变更

用户已明确不需要制动电路，本轮不新增制动支路，也不以制动参数未提供阻止其他修复。S03仍仅记录尚未验证的系统浪涌/回馈工况；取消电路不构成该系统资格的通过证据。

## 原厂依据与后续证据

- [TI SN74LVC3G17 Rev.F](https://www.ti.com/lit/ds/symlink/sn74lvc3g17.pdf)：§6.3工作温度与§6.6时序表应分开使用。
- [SICK VFS60系列官方产品资料](https://www.sick.com/media/docs/8/28/628/product_information_vfs60_motor_feedback_system_rotary_incremental_en_im0022628.pdf)：2013年版第4页5V差分档预算实例；不作为当前采购或通用编码器承诺。另核查的DFS60B-BACA02048具体型号实际为10..32V，不能因系列通用图出现5V就当成5V型号。
- [Ohmite 650FPR005E](https://www.ohmite.com/catalog/60-series/650FPR005E/)：5W、1%、100ppm/°C；完整温度/寿命/装配资格仍需补齐。
- [TI LM74502](https://www.ti.com/product/LM74502)：反接保护不包含反向电流阻断。

以上是热设计输入、计算及编码器候选供电合同，没有新增实体波形或热浸证据。PCB候选的原生DRC结果另见[铜线修复记录](pcb_legacy_route_repair_2026-10-10.md)。

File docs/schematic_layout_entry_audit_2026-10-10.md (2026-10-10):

# AX7010 Servo Rev.A 原理图及 PCB layout 准入审计报告

审计日期：2026-10-10。审计方式：只读设计审核、新鲜原生导出、物理网表追踪、厂商资料复核及逐页图面检查。

## 1. 放行结论

**正式布局布线：BLOCKED。当前不能称为“原理正确无误、可直接进入正式 PCB layout”。**

原生连接及结构检查已经通过，许多旧接线缺陷确已修复。但是 ADC 欠压许可存在确定缺口；相 shunt 不覆盖内部桥臂直通；回馈/浪涌、功率额定边界、关键选型及若干接口功能仍未闭合。这些项目可能改变电路拓扑、器件数量或机械空间，应先于正式相关区域布线处理。

| 阶段 | 决定 | 条件与边界 |
|---|---|---|
| 机械及功能分区、可撤销摆件研究 | PARTIAL，可开展 | 标明保护/电源/接口未冻结区域，保留新增检测、制动、连接器和测试点空间；不能作为终版布线依据 |
| 以当前电路为冻结输入开展正式布局布线 | BLOCKED | 关闭本报告列为“正式layout前”的设计决定；按区域放行必须明确该区域无未决拓扑/关键封装依赖 |
| 布局/布线冻结 | BLOCKED | 除上述项，还须完成动态设计界限、关键封装/接口/规则审核和PCB闭环 |
| 投板、功率上电、量产资格 | BLOCKED | 当前PCB有真实短路、478未连接；制造、低能量验证及热/保护实测均不能由本报告替代 |

台架波形需要样机，**不把尚无样机的全部实测项目一概要求在首次布局前完成**。但保护架构、可计算的额定界限、准确封装和接口必须先有明确设计输入。Gate B保持开放并不禁止受控样机设计；它禁止宣称功率保护/制造资格已经完成。

本报告的PASS仅覆盖明确列出的检查。未取得器件动态保证、真实负载或实测证据的项目，分别列为资格缺口；不把缺少证据写成“已证实一定失效”。

## 2. 实际审计基线

| 项目 | 本次值 |
|---|---|
| 源提交 | `58ddc5e29ff316f34002cf973014cde1fd32f42d` |
| 审计分支 | `audit/schematic-layout-entry-20261010`；从最新main同一提交创建，未提交、未推送 |
| 源文件 | KiCad 10原生顶层＋七子页；旧.sch/.lib不作为源 |
| 工作区 | `.kicad_pro`已有232行本地新增设置，纳入实际ERC/DRC基线；原本未跟踪的教程产物和hardware/.history不动 |
| 工具 | KiCad CLI/pcbnew 10.0.3；本机Python 3.13.9；ngspice-46共享DLL。仓库推荐3.12，本轮未验证3.12 |
| 规格 | 24..48V、20kHz、10A连续相电流；10Arms为暂定计算解释，峰值/环境/散热/回馈包络未冻结 |
| 系统原生XML | 159对象 / 167网络 / 648物理引脚节点，包括板外F1/J6 |
| 板级原生网表 | 157元件 / 166网络；PCB161封装=157电气＋H1..4机械 |
| 装配属性 | DNP：D1、R32、RT1..3；板外：F1/J6。J2实际不是DNP |
| BOM | 159行，值/封装/MPN字段与新网表无差异；120对象MPN为TBD |

原始证据目录：[artifacts/schematic-audit/20261010](../artifacts/schematic-audit/20261010/)。`manifest.json`保存检查命令、退出码及源哈希；`analysis.json`保存派生统计。648引脚附表是连接追踪底稿，**不等于648个引脚均完成独立厂商应用资格认证**。

## 3. 新鲜检查结果及限制

| 检查 | 本次结果 | 说明 |
|---|---|---|
| XML、板级网表、独立BOM、完整PDF导出 | exit 0 | 均从当前原生层次生成；未运行会覆盖hardware/bom.csv的旧导出脚本 |
| 原生ERC | exit 0；8页，0错误/0警告/0排除 | 报告包含error/warning/exclusion；继承4类ignored_checks，见下表 |
| 六项源检查 | 全部exit 0 | native_schematic、kicad_grid、schematic_layout、schematic_connectivity、power_wiring、design |
| 安全网表 | exit 0 | 157元件/166网，逐物理脚关键连接回归 |
| OCP稳态行为 | exit 0，531场景 | 不含亚稳、模拟延迟、斜坡、脉宽或真实开关模型 |
| 逐焊盘PCB parity/约束 | 均exit 0 | 元件/焊盘/网络一致，不能证明现有铜无短路 |
| PCB检查器回归 | 11项通过 | 真实错误网、缺器件/焊盘等回归 |
| 教程静态检查器回归 | 4项通过 | 工具本身仍有off-board误报，S17 |
| 统一入口回归 | 2项，1通过/1跳过 | 跳过要求ngspice CLI及POSIX可执行脚本的用例 |
| Gate A/B回归 | 18项，16通过/2跳过 | 使用本轮XML执行物理网表mutation；跳过ngspice CLI及POSIX相关用例 |
| Gate A/B资格检查 | exit 2，A/B均BLOCKED | 物理合同通过；严格门禁未关闭。低层qualification.json的ERC=NOT_RUN指该工具不执行ERC，本次ERC以erc.json为准 |
| 被动/理想源仿真 | exit 0；6个deck，解析交叉验证通过 | 使用本机ngspice DLL；缺spinit提示保留。无厂商有源器件/开关/热模型，不能替代被跳过的CLI测试 |
| 教程辅助静态parity | exit 2 | F1/J6板外属性误报，已解释但未修改/隐藏原始结果 |
| 原生DRC | exit 5 | 271违规=220错误/51警告；478未连接；0原生schematic parity问题；未保存PCB |
| 源文件完整性 | 前后SHA256完全一致 | 最终交付另复核；不读取环境变量值或.env |

**继承忽略类型**（不是本次新增，未降低任何严重级别）：

| 报告 | ignored_checks |
|---|---|
| ERC | single_global_label、four_way_junction、simulation_model_issue、footprint_filter |
| DRC | missing_courtyard、track_not_centered_on_via、tuning_profile_track_geometries、footprint_filters_mismatch、footprint_type_mismatch |

零exclusion不等于零ignored。项目脚本检查T分支/层次连接不能替代全部原生ERC类别；封装过滤器、类型和庭院仍须独立审阅。单次使用的全局标签检查被忽略；仿真模型问题检查被忽略也不能证明模型合格。

DRC按类型：间距113、阻焊桥88、孤立铜43、跨网短路17、悬空走线8、走线交叉2。当前20条历史走线、0过孔、5个zone，实际板网180个；其中旧网名不能当成仍有效的原理图网络。上述数量来自本轮报告，不抄用2026-10-09历史记录。

## 4. 逐功能/逐页审查

### 4.1 系统、电源输入和母线（第1、2页）

新图及网表确认：外置电源J6正极→F1→VIN_FUSED→J3.1→Q7/U18；J3.2为GND。Q7/Q8共源背靠背：Q7.5在输入，Q8.5在VBUS_PROT，U18.8接公共源，.6接门极，.4电荷泵电容返回VS。U18的NC3保持NC，OV7接地是明确禁用OV，不是漏接。[LM74502原厂手册][D3]的脚序及基本应用相符。

D1 K1/A2与图/封装一致，但实际DNP；不以TVS图形存在认定已有钳位。C1/C2各100uF，48V标称储能0.2304J。母线分压R1/R2=280k＋280k，R3=39k：24/48V分别1.5626/3.1252V；C5=10nF，时间常数364.608us，截止436.51Hz。这是慢监测，不能充当快速硬件OV保护。高侧两只电阻分担电压，但准确耐压/温漂尚待选型。

Q7/Q8标称每只4mΩ只适用于厂家相应VGS/温度测试条件。假设母线电流10A时两管导通损耗约0.8W，仅为示例；相电流10Arms并不能推出母线电流10A。浪涌、回馈、保险配合及散热分别按S03/S05/S21处理。

### 4.2 AX7010接口（第3页）

采用官方公开V2原理图第5/15页及官方手册J10表交叉复核。公开图纸标题栏日期2018-10-08，厂商仓库名2023.1表示教程/工具版本，不能冒充2022实板测量。新下载原厂PDF哈希与历史缓存一致：`e35eb1b654774a6f314de0140f5608d38a1c6be72d1c3e1008f5e288ac83c87e`。

J1.1/.37/.38为GND，.2保持NC，.39/.40为3.3V；37/38的地符号在厂商图中旋转绘制，已放大确认，不应误读成IO。J1.3..8六PWM、.9 EN、.10 CLEAR、.11..18 ADC、.19..21 ABZ、.23 OCP、.24 PGOOD与现行XDC及厂商活跃脚映射相符。R80..86七个10k真实连接六PWM与EN，配置期偏置存在。

J1.22以及辅助/备用信号为真实NC；XDC中的ENC_FAULT_N/AUX/SPARE预留并不实现这些接口。J2当前只有电源/地连接，信号NC；图面“DNP”与真实属性不一致见S15。线缆方向、回流、电源预算和实际FPGA工程仍按S10验证。

### 4.3 辅助电源（第4页）

U12 LM5164的VIN/EN接VBUS_PROT，GND/EP接GND，BST电容跨BST/SW，68uH接SW到12V；R20=100k，反馈453k/49.9k，Type-3 ripple网络453k/3.3nF/56pF关系与原厂示例相符。1.2V反馈基准下理想电阻比为12.0938V，实际COT纹波注入与误差会改变稳态值，不能据此报成已测输出。按12V/300kHz/68uH理想CCM计算，24/48V时纹波约0.294/0.441App；1A负载时峰值约1.147/1.221A。44uF名义输出电容只给约2.79/4.18mV纯电容纹波，不含偏压/ESR/瞬态。[D8]

L1真实料号为Coilcraft MSS1246T-683MLC，25°C表中饱和/温升电流不能直接搬到高温；L2真实料号74438356022，原厂新手册003.002/2026-09-01有电流及PCB热测试条件。未发现“2.2uH显然不足以支撑1A”的证据；仍须按电感容差、热与芯片限流上界计算。[D14][D15]

U13 TPS62163DSGR是固定5V型号；.5 FB→AGND，.6 VOS→5V，.1/.4/.9接GND，.7→L2，.8为PG。不是应补分压的可调TPS62160。输入12V在推荐3..17V内；2.2uH＋22uF属于厂商常见应用组合。两buck开漏PG并接并由VIO拉高，其高阻/失电行为与共享编码器负载见S08/S09。[D9]

### 4.4 电流采样、ADC及OCP（第5页）

U2..4：pin8 IN+接对应SW，pin1 IN−接PH，pin6供电；pin7 REF1接VA5、pin3 REF2接GND，pin2及必须接地的保留pin4均接地。C43..45已正确跨供电/GND，不再是两端落地。A2增益20、5mΩ shunt得到0.1V/A，零位跟随VA5/2；±10A在5V标称时输出1.5/3.5V，±25A触理想电源轨不能当作保证量程。[D4]

U6串行模式所需pin16..22/27..33均接地，不再沿用13脚NC旧错误；OS=000、PAR/SER高、STBY高、RANGE低、REFSEL高。四AVDD去耦、DVDD去耦、两独立REGCAP电容和REFCAPA/B短接去耦关系正确。三个测流输入为49/51/53，母线55，两个温度57/59，未使用模拟通道及负输入接地；BUSY/DOUT/RESET等与J1对应。[D2]

U15高限比较器是IN−接测流、IN+接高参考，过高拉低；U16低限是IN+接测流、IN−接低参考，过低拉低，六个开漏输出并入OCP_N并经4.7k拉到VIO。未用第四比较器两输入接GND、输出NC，不参与OCP。名义参考高/低4.705882/0.294118V，名义阈值±22.0588A。仅VA5±5%、阈值电阻±0.1%、shunt±1%时约20.743..23.402A；还未计入IC、温度、动态。[D5]

47Ω/1nF的3.386MHz网络不是完整20kHz抗混叠滤波；ADC和OCP共用节点，不能为美化采样单独加大C而不重算保护。ADC±5V量程的理想电流码宽约1.526mA/LSB，不等于实际测流精度。S01/S04/S12/S20仍开放。

### 4.5 门驱动及逆变桥（第6页）

FD6288T按原厂V1.6 p6核对20脚：1..3 HIN、4..6 LIN、7供电、8 COM，9/10/11对应W/V/U低侧，12/15/18对应W/V/U VS，13/16/19对应HO，14/17/20对应VB。新网表与此对应；六MOS的S1..3/G4/D5及高低桥臂连接正确。六10Ω栅阻及10k栅源电阻有真实局部回路。[D6][D7]

D2..4阴极pad1接BST、阳极pad2接12V，CBOOT跨BST/SW，极性旧缺陷未复现。名义1uF按Qg72nC算一次充电降压0.072V，仅是单项示例；**持续高侧导通还必须包含VGS/10k的栅源电阻负载**，以及静态耗流、漏电和有效容量。驱动内部互锁/死区确实存在，不能误写成“FD6288没有互锁”；也不能据此宣称所有MOS短路故障受到保护。S02/S04/S07为本区域关键门禁。

四端shunt的force1/2和sense3/4左右对应关系正确、同侧同网是有意建模；Kelvin不能由网名区分保证，必须让感测走线独立从3/4焊盘引出，不共享负载铜。

### 4.6 编码器（第7页）

U7 AM26LV32E的三对输入、输出和使能脚均与厂商图对应，VCC=VIO；输出电平属于FPGA同域，但尚未证明线缆输入及部分供电行为。U19已是正确RVZ14脚映射，不再使用旧错误封装；NC1/2/3/4/6/7无须为ERC强接，5/10接GND，六IO接A/B/Z正负。[D10][D11]

RT1..3确为DNP，不是默认已端接；J5.9 SHIELD确为NC，不是已有屏蔽回路；F2仅值“0.5A PTC”不代表硬限流。尤其要区分接收器-7..7V共模能力与U19 0..5.5V工作范围，见S11。

### 4.7 硬件锁存和复位（第8页）

U20 pin1 CLK来自CLEAR→1k/1nF→U21 Schmitt，pin2 D来自反相GATE_EN，pin6 /CLR来自U23健康组合，pin7 /PRE拉高，pin5 Q=ARMED；/Q未使用。U23组合OCP_OK、PWR_READY和POR_OK；U11组合EN、PWR_READY、ARMED。U24检测VIO、U25由VIO供电检测VA5，CT悬空是12..28ms恢复延时选择，不是遗漏电容。[D1][D12]

稳态逻辑满足：故障清除Q；单纯故障恢复不恢复Q；新CLEAR上升沿只有EN低且健康时能装载1；CLEAR一直高穿过故障不会自动重武装。531场景仅证明这些稳态条件，不能验证最小故障脉冲、恢复/清除竞争和上电模拟行为。U26/SN74LVC3G17 Rev.F推荐工作温度为−40..125°C，但开关时序表保证范围仅为−40..85°C，不能据此保证125°C的关断延迟；准确订货码温度资格及全板环境额定仍须核对。[D13]

## 5. 可追踪发现与关闭条件

P0：明确的安全许可设计缺口，优先修复；P1：功能/保护覆盖、关键额定/接口/封装缺口或本阶段阻塞项；P2：装配、说明和辅助工具问题。严重度与证据类型分别记录。下列条目均OPEN，不意味着每一条均是已证实的接线错误。

| ID | 等级 | 类型 | 对象 | 发现 | 关闭阶段 |
|---|---|---|---|---|---|
| S01 | P0 | 已确认设计缺口 | U25/U6/U20/U11 | ADC 模拟供电失效区仍可能允许 PWM | 正式 layout 前关闭 |
| S02 | P1 | 已确认保护覆盖缺口 | Q1..Q6/RSH1..3/F1 | 相电流 OCP 不覆盖桥臂内部直通故障电流 | 正式功率布局前确定保护架构 |
| S03 | P1 | 已确认拓扑＋系统证据缺口 | D1/U18/C1/C2/Q7/Q8 | 回馈吸收及正向过压保护未闭合 | 正式功率布局前确定方案；投板前完成额定验证 |
| S04 | P1 | 动态资格缺口 | U2..4/U15/U16/U26/U23/U20/U11/U8..10/U1/Q1..6 | 全链路 OCP 延迟与 MOSFET SOA 未建立最坏界限 | 布局冻结前有设计界限；样机功率试验前实测 |
| S05 | P1 | 规格缺口 | 整机/Q1..8/RSH1..3/J3/J4 | 峰值、10A定义、环境与散热尚未冻结 | 正式功率布局前关闭 |
| S06 | P1 | 选型资格缺口 | C1..4/C20..23/C30..31/CBOOT1..3/F2/NTC1..2/D2..4/J1/J2/J5及相关R | 120项 MPN 为 TBD，关键无源及接口额定条件未冻结 | 关键封装/额定件在正式相关区域 layout 前；其余投板前 |
| S07 | P1 | 应用资格缺口 | U1/D2..4/CBOOT1..3/RG1..6/RGS1..6 | Bootstrap、最长高侧保持及死区未与实际工况配合 | 正式驱动布局前完成设计计算；冻结前动态验证 |
| S08 | P1 | 负载/稳压资格缺口 | U12/U13/L1/L2/C20..31/J5/F2 | 辅助电源拓扑正确，但全负载、启动及有效容量预算未闭合 | 正式电源区域 layout 前完成预算；投板前验证 |
| S09 | P1 | 电源时序资格缺口 | VIO/VA5/VDRV/U12/U13/U24..26/U6/U1 | 部分供电、PGOOD高阻及欠压时的关断/恢复尚无完整证明 | 正式相关区域 layout 前确定策略；样机前完成验证方案 |
| S10 | P1 | 接口/电源预算缺口 | J1/J2/AX7010/U7/U24 | VIO最低值、负载余量与线缆条件未资格化 | 接口布局冻结前；实板连续性在连接前 |
| S11 | P1 | 接口适配资格缺口 | U7/U19/J5/F2/RT1..3 | ESD阵列的工作范围未与编码器共模、端接和供电协调 | 正式编码器区域 layout 前确定电气边界 |
| S12 | P1 | 已确认功能定义缺口 | NTC2/R71/U6.59 | NTC_MOTOR当前没有外部电机测温接口 | 正式相关区域 layout 前确定 |
| S13 | P1 | 封装装配资格缺口 | U1/U2..4/U6/U12/U13/U18/U19/Q1..8/RSH1..3/J3/J4 | 物理引脚一致性通过，但全部关键land pattern尚未完成装配验收 | 相关器件布线冻结前 |
| S14 | P1 | 已确认PCB基线缺陷 | 20条遗留铜线/5个zone/全板 | 旧铜线仍造成真实跨网短路，不能在该状态上直接继续布线 | 正式新增布线前清理；最终DRC在投板前关闭 |
| S15 | P2 | 已确认装配信息不一致 | J2 | J2图面写DNP，但原生属性与BOM为装配 | BOM/接口冻结前 |
| S16 | P2 | 已确认文档版本漂移 | 顶层/电源页标题栏及旧报告 | 旧15..55V、15A/25A等叙述仍混在当前工程中 | layout交接前 |
| S17 | P2 | 已确认辅助工具误报 | board_parity_audit.py / F1/J6 | 辅助静态审计未识别off-board属性 | 审计工具修复；不阻塞电气layout |
| S18 | P2 | 已确认派生证据描述错误 | gate_ab_verify.py/qualification.json | corner_basis把INA REF1/REF2文字写反 | 审计工具修复；不阻塞电气layout |
| S19 | P1 | 继承规则/布局资格缺口 | project rules / PCB | 继承忽略项及电流/间距规则需显式审核 | 布局冻结前审定；投板前全部闭合 |
| S20 | P1 | 采样/控制时序资格缺口 | U2..4/U6/R40..42/C40..42/FPGA | 电流链采样窗口、抗混叠和复位时序未闭合 | 布局冻结前确定接口时序；样机验证 |
| S21 | P1 | 系统保护配合缺口 | F1/holder/J3/源及线束 | 25A外置保险尚未按现行10A目标完成配合 | 正式输入功率布局前确定边界；功率上电前验证 |

### S01 · P0 · ADC 模拟供电失效区仍可能允许 PWM

- 对象/来源：U25/U6/U20/U11；ocp_latch / current_adc。
- 证据：新网表：U25.5=VA_5V，U25.6=VIO_3V3；U25 为 TPS3808G50。ADS8588S AVDD 下限 4.75V；G50 全温保守下降阈值 4.557..4.743V，-40..85°C 为 4.58025..4.71975V。无独立 ADC_VALID 硬件许可。来源 [D1][D2]、qualification.json。
- 影响与根因：VA5 下降时 ADC 可先失去规定精度/功能，而 ARMED/RUN_OK 尚未保证关闭。独立模拟 OCP 的存在不能证明采样闭环仍正确。7mV 只是采用最早动作角点时的最小窗口，典型约100mV，不能当成最坏窗口。
- 建议修复：优先设计覆盖 ADC 工作下限的硬件许可/监督，并把它纳入门控和故障锁存；阈值须计入检测误差、迟滞、纹波、下降速率和检测到 VGS 关闭的总时延，不直接照抄4.75V标称。
- 关闭标准：提供可满足“最迟关断时 ADC 仍有效”的最坏角点计算；新网表证明无效许可能异步关断并锁存。下降/上升、慢坡/快速跌落、随机上电次序和 CLEAR 竞争先做适用模型验证，样机再实测。
- 阶段：正式 layout 前关闭。状态：OPEN。

### S02 · P1 · 相电流 OCP 不覆盖桥臂内部直通故障电流

- 对象/来源：Q1..Q6/RSH1..3/F1；gate_inverter / power_input。
- 证据：U相：Q1.5=VBUS_PROT，Q1.1..3=Q2.5=SW_U，Q2.1..3=GND；RSH1 串在 SW_U 与 PH_U 间。V/W 同理。analysis.json 保存三条路径证明。
- 影响与根因：VBUS_PROT→上管→下管→GND 绕过相 shunt；正常命令互锁不覆盖 MOSFET 短路等故障。源端 F1 也不在板上 DC-link 电容局部放电路径中。此项不表示正常 PWM 必然直通。
- 建议修复：编制电机过载、相线短路、上下管/门驱故障、母线短路覆盖矩阵；对必须覆盖的故障选定独立母线/器件电流检测和快速关断/能量限制方案。不能仅以 FPGA 死区或25A保险视为闭合；若依赖系统限能，须证明能约束板载电容及源侧能量。
- 关闭标准：每类故障列出被检测电流路径、执行器、最坏能量与允许器件应力；需要增加的检测/关断元件在功率铜和连接器布局前落实。样机破坏性短路试验不属于本次审计。
- 阶段：正式功率布局前确定保护架构。状态：OPEN。

### S03 · P1 · 回馈吸收及正向过压保护未闭合

- 对象/来源：D1/U18/C1/C2/Q7/Q8；power_input。
- 证据：D1=SMCJ54A 且 dnp；U18.7(OV)=GND；C1+C2=200uF。LM74502 只做反接、无反向电流阻断，VS 推荐最高60V/绝对最高65V。spice/results.json：理想无吸收1A由48到55V需1.4ms。来源[D3]。
- 影响与根因：回馈或输入浪涌可能超过控制器/下游器件范围。200uF 不是已合格制动器；55V 是演示值，不是安全上限。即使把D1装上，也必须校验动态钳位电压、源端U18所处位置和能量。
- 建议修复：冻结电源可回充能力、最大机械/感性能量及断电状态；优先明确系统回馈吸收/制动及源侧浪涌保护边界，再决定板载OV、钳位及预留接口。不能只把D1改成装配。
- 关闭标准：用实际能量、源阻抗和线缆寄生证明各节点低于其带裕量工作限值；钳位/制动元件能量、温升和故障状态有计算，拓扑和必要封装在功率布局前确定。
- 阶段：正式功率布局前确定方案；投板前完成额定验证。状态：OPEN。

### S04 · P1 · 全链路 OCP 延迟与 MOSFET SOA 未建立最坏界限

- 对象/来源：U2..4/U15/U16/U26/U23/U20/U11/U8..10/U1/Q1..6；current_adc / ocp_latch / gate_inverter。
- 证据：实际路径为 INA→47Ω/1nF→TLV9024开漏→U26→U23/U20→U11/U8..10→FD6288→MOSFET。531项回归仅稳态布尔行为。TLV9024速度典型值、FD6288 25°C/15V时序、Qg/峰值电流比均不能成为本工况全温保证。来源[D4][D5][D6][D7]。
- 影响与根因：高 di/dt 故障在关断前可能超过器件应力；相电流正好越阈值时的低过驱会影响延迟。数字32ns预算不是从故障发生到VGS关闭的上界。
- 建议修复：按故障斜率、INA恢复、比较器过驱和开漏RC、逻辑负载、栅阻与温度建立分项预算；核对驱动器保证条件和MOS SOA，缺失保证值时留为未证明，不用典型值补齐。
- 关闭标准：布局前确定所需最短保护路径、测试点和寄生约束；冻结前有受约束的设计预算，样机低能量验证真实电流/OCP_N/六路VGS并校正预算。
- 阶段：布局冻结前有设计界限；样机功率试验前实测。状态：OPEN。

### S05 · P1 · 峰值、10A定义、环境与散热尚未冻结

- 对象/来源：整机/Q1..8/RSH1..3/J3/J4；system / design_calculations。
- 证据：本次授权基线24..48V/20kHz/10A连续相电流；10Arms仅用于计算。未给出峰值及持续时间、最高环境、冷却/机壳、最大电机能量。
- 影响与根因：铜厚/铜面积、端子、shunt、MOSFET、保护阈值和制动设计无法得到一致最坏工况。不能沿用历史15A连续或25A/5s作为已确认要求。
- 建议修复：形成唯一额定规格表并计算正常峰值、保护阈值、母线电流、热及能量包络。优先锁定会改变器件尺寸和功率布线的项目。
- 关闭标准：规格有可追溯确认；保护阈值在全部误差下高于允许工作电流且低于允许故障应力；热预算据此重算。
- 阶段：正式功率布局前关闭。状态：OPEN。

### S06 · P1 · 120项 MPN 为 TBD，关键无源及接口额定条件未冻结

- 对象/来源：C1..4/C20..23/C30..31/CBOOT1..3/F2/NTC1..2/D2..4/J1/J2/J5及相关R；BOM / all sheets。
- 证据：新系统网表159对象、BOM159行，值/封装/MPN字段无差异；120对象MPN缺失，包括外部J6及非关键被动件，不能把120全部算成电气错误。全部23颗IC、8颗MOSFET已有型号字段。component_inventory.csv可逐项筛选。
- 影响与根因：电容有效容量/ESR/纹波、分压电阻耐压/TCR、PTC动作与阻值、NTC曲线、二极管恢复和连接器额定值无法由名义值及通用封装证明。C3描述FILM但指向通用1210尤其需采购可实现性核验。
- 建议修复：先冻结影响机械或安全的电容、bootstrap二极管/PTC/连接器及精密阈值电阻；普通电阻可按明确容差、功率、耐压、TCR的受控替代表管理，不强求每颗先指定唯一厂家。
- 关闭标准：关键器件准确订货码或受控规格可追溯，额定及DC偏压/温度降额满足计算，封装与采购实物一致；不得仅清空TBD字符串。
- 阶段：关键封装/额定件在正式相关区域 layout 前；其余投板前。状态：OPEN。

### S07 · P1 · Bootstrap、最长高侧保持及死区未与实际工况配合

- 对象/来源：U1/D2..4/CBOOT1..3/RG1..6/RGS1..6；gate_inverter。
- 证据：新网表D2..4 K1→BST，A2→12V，CBOOT=1uF跨BST/SW；RG=10Ω，RGS=10k。FD6288 V1.6 p4/10..14有自举、UVLO、互锁和死区条件；内部死区100..300ns为25°C/15V条件。资料[D6]为本地厂商缓存。
- 影响与根因：1uF标称不等于有效容量；高侧10k栅源电阻本身持续耗用bootstrap电荷，不能只算Qg。无刷新下不能保证无限期100%高侧导通；内部互锁不自动证明实际MOSFET交越安全。
- 建议修复：用有效C、Qg、VGS/RGS、IQBS、漏电与二极管压降计算最低VBS、最大保持和最低刷新；定义预充、PWM最小脉宽/最大占空比及外部死区。复核ES1J准确型号和恢复；厂商偏好Schottky不等于ES1J必然错误。
- 关闭标准：最坏VBS及VGS同时满足驱动和MOS导通要求；时序预算覆盖真实温度/负载，预充和刷新协议写入接口要求；六路波形在样机低能量阶段验证。
- 阶段：正式驱动布局前完成设计计算；冻结前动态验证。状态：OPEN。

### S08 · P1 · 辅助电源拓扑正确，但全负载、启动及有效容量预算未闭合

- 对象/来源：U12/U13/L1/L2/C20..31/J5/F2；aux_power / encoder。
- 证据：LM5164外围与原厂12V/1A/300kHz示例同类；TPS62163为固定5V，FB接GND/VOS接5V。L1=MSS1246T-683MLC，L2=74438356022，5V还直接供编码器。来源[D8][D9][D14][D15]。
- 影响与根因：1A芯片额定不等于编码器可取1A；编码器短路/启动可拖低ADC/OCP电源。磁件热、电容DC偏压和启动时MOS栅极状态未被理想RC仿真覆盖。
- 建议修复：分别预算12V门驱＋5V转换输入、5V ADC/INA/比较器＋编码器、VIO逻辑；纳入效率、浪涌及PTC慢动作。计算纹波/峰值并按真实电容和电感降额核验，必要时改变编码器供电隔离/限流策略。
- 关闭标准：三轨最坏负载有余量，最低输入/最高温度启动和阶跃满足电压窗口；编码器故障时硬件安全链满足S01/S09。
- 阶段：正式电源区域 layout 前完成预算；投板前验证。状态：OPEN。

### S09 · P1 · 部分供电、PGOOD高阻及欠压时的关断/恢复尚无完整证明

- 对象/来源：VIO/VA5/VDRV/U12/U13/U24..26/U6/U1；aux_power / ocp_latch / current_adc。
- 证据：U24/U25均由VIO供电，U25检测VA5；两个buck的开漏PG并网并由VIO上拉。TPS62163关断时PG可高阻。三域八种稳态要求列在power_domain_matrix.csv；全供电仍须健康且有新CLEAR沿。来源[D1][D2][D9]。
- 影响与根因：PG高并不单独证明所有模拟域有效；电容残压、短暂掉电及重新恢复可能与锁存状态竞争。Ioff能力或下拉电阻不能替代所有坡形/残压条件的证明。
- 建议修复：枚举八稳态、六上电/六掉电顺序及毛刺；分析PG关闭条件、残压、门驱UVLO、ADC数字/模拟供电约束和引脚灌电；必要联锁变更在相关区域布局前落实。
- 关闭标准：模型/静态分析清楚区分能证明与未知的组合；任何不允许域组合下六路驱动为低，恢复不自动重新武装。样机测试覆盖真实坡形、极短失电及CLEAR相位。
- 阶段：正式相关区域 layout 前确定策略；样机前完成验证方案。状态：OPEN。

### S10 · P1 · VIO最低值、负载余量与线缆条件未资格化

- 对象/来源：J1/J2/AX7010/U7/U24；ax7010_interface / XDC。
- 证据：新网表J1.1/.37/.38=GND，.2=NC，.39/.40=VIO；3..24活跃脚与官方J10表和XDC一致。G33全温保守释放约3.194V。AM26LV32E要求VCC≥3.0V。ALINX公开V2图纸日期2018，不能当成2022实板连续性记录。来源[D1][D10][D16]。
- 影响与根因：VIO线缆压降及动态负载可能使监督器不释放或接收器离开规格；信号返回、线缆方向及FPGA位流引脚冲突未实测。
- 建议修复：确定线缆、方向/防反插、实际AX7010电源可用电流和最小端电压，计算所有VIO负载及逻辑电平裕量；实物逐针确认并按实际Vivado工程核查占用。
- 关闭标准：最坏VIO满足监督恢复、接收器和逻辑条件；J10接线/Bank电压可追溯。接口文档/XDC/实板三者一致，不能把预留XDC端口视为已接线。
- 阶段：接口布局冻结前；实板连续性在连接前。状态：OPEN。

### S11 · P1 · ESD阵列的工作范围未与编码器共模、端接和供电协调

- 对象/来源：U7/U19/J5/F2/RT1..3；encoder。
- 证据：U19 RVZ14脚序现已正确：IO=14/13/12/11/9/8，GND=5/10。TPD6E05U06建议IO为0..5.5V，AM26LV32E接收共模可达-7..+7V；实际编码器/线缆未知。RT1..3=120Ω DNP，SHIELD脚NC，F2无准确型号。来源[D10][D11]。
- 影响与根因：接收器共模能力不能移植到整个带ESD的端口；超出阵列范围时可能钳位或失真。端接、地偏移和编码器电源短路影响也未定。不能据此断言当前5V编码器一定不能工作。
- 建议修复：冻结编码器电平/最大频率、共模/地偏移、线缆阻抗和长度；按该包络选择保护、端接装配及屏蔽连接。为F2选定保持/动作电流及热阻曲线，核验共享5V故障行为。
- 关闭标准：端口内每颗器件均覆盖正常/故障电压包络；末端120Ω的装配策略和屏蔽/机壳回路有定义，原理图及BOM同步。
- 阶段：正式编码器区域 layout 前确定电气边界。状态：OPEN。

### S12 · P1 · NTC_MOTOR当前没有外部电机测温接口

- 对象/来源：NTC2/R71/U6.59；current_adc / architecture。
- 证据：NTC_MOTOR只连接R71.2、NTC2.1、U6.59；NTC2为板载0603，所有外部连接器均无该网。架构称CH6为motor/connector NTC。physical_pins.csv与新图面第5页。
- 影响与根因：当前只能测板载NTC2所在位置温度，不能证明测得电机绕组温度；软件命名可能形成错误保护预期。
- 建议修复：若需要电机外置NTC，增加明确连接器/回流、线缆滤波和ESD、开短路诊断并选定传感器；若只测板/端子温度，则明确收窄功能并更名，不能保留“电机测温已实现”表述。
- 关闭标准：测温对象、物理安装位置、接口和BOM一致；外部方案有开路/短路/热插拔的ADC与保护测试。
- 阶段：正式相关区域 layout 前确定。状态：OPEN。

### S13 · P1 · 物理引脚一致性通过，但全部关键land pattern尚未完成装配验收

- 对象/来源：U1/U2..4/U6/U12/U13/U18/U19/Q1..8/RSH1..3/J3/J4；symbols / footprints / PCB。
- 证据：23颗IC型号及关键引脚人工对照厂商资料；所有嵌入与本地库pin-name/type/number无差异。26个关键封装已只读提取。J3/J4为9.52mm节距/1.3mm钻孔；shunt为25.4×6.35mm/2.6mm钻孔，H1孔3.2mm。见board_geometry.json。
- 影响与根因：同名封装、引脚编号相同不能证明焊盘、阻焊/钢网、引脚公差和装配空间完全合格；多处采用通用KiCad IPC焊盘而非原厂样例。
- 建议修复：对准确订货码逐一签核外形、pin1、EP、焊盘、阻焊/钢网和工艺公差；大端子/shunt核验壳体、钻孔和实物装配。保留已正确的映射，不重新赋占位封装。
- 关闭标准：每类关键封装有尺寸对照、可制造性和装配责任确认；本地shunt/端子有样件或公差链支持，布局保留维修、线束和紧固空间。
- 阶段：相关器件布线冻结前。状态：OPEN。

### S14 · P1 · 旧铜线仍造成真实跨网短路，不能在该状态上直接继续布线

- 对象/来源：20条遗留铜线/5个zone/全板；PCB。
- 证据：新原生DRC：271条=220错误/51警告，478未连接，parity0。分组：clearance113、solder_mask_bridge88、isolated_copper43、shorting_items17、track_dangling8、tracks_crossing2。旧线仍有VBUS/PGND/U_SH_N等旧网名。
- 影响与根因：图板焊盘parity0仅说明预期分配一致，不会消除实际跨网铜短路。现有板不能上电；普通布局移动也不能被视为这些铜已合格。
- 建议修复：另开PCB修复任务，先保存板快照及机械特征，逐条追踪20条旧线及5个zone，批准后重建失效铜，保留正确网络与机械对象；不得无记录清空所有铜或用排除项消数。
- 关闭标准：旧网铜和17条短路报告逐项闭环后再开始正式新布线；完成板最终要求原生DRC/未连接/parity均0，且没有新增掩盖性忽略。
- 阶段：正式新增布线前清理；最终DRC在投板前关闭。状态：OPEN。

### S15 · P2 · J2图面写DNP，但原生属性与BOM为装配

- 对象/来源：J2；ax7010_interface / BOM。
- 证据：第3页标注“J2 unused expansion (DNP)”；新XML无J2 dnp属性，BOM状态Fitted，真实DNP列表只有D1/R32/RT1..3。
- 影响与根因：装配和线缆使用可能与说明不一致；J2电源/地仍连接，不能把图中文字当成有效DNP。
- 建议修复：统一J2是否装配的政策，在原生dnp属性、BOM和注释中保持一致；若装配，注明信号当前NC及电源连接。
- 关闭标准：新独立BOM/XML/图面三者一致，并保留未使用信号的真实NC状态。
- 阶段：BOM/接口冻结前。状态：OPEN。

### S16 · P2 · 旧15..55V、15A/25A等叙述仍混在当前工程中

- 对象/来源：顶层/电源页标题栏及旧报告；schematic annotations / historical docs。
- 证据：新图第1页注释仍为48V nominal;15..55V full-function，第2页仍15..55V design window；旧封装报告仍写15A连续/25A短峰值。当前授权24..48V/10A。
- 影响与根因：布局和后续修复可能按过时包络选件或以55V作为允许值；这不代表连接图本身已改变。
- 建议修复：后续单独修订当前有效注释和文档基线；历史记录保留但加明确被替代说明，禁止把历史证据改写成新执行结果。
- 关闭标准：设计输入只有一套现行规格；计算示例越界电压与允许工作电压明确区分。
- 阶段：layout交接前。状态：OPEN。

### S17 · P2 · 辅助静态审计未识别off-board属性

- 对象/来源：board_parity_audit.py / F1/J6；static audit。
- 证据：static_parity exit2仅将外置F1/J6列为缺板/缺封装；二者XML明确exclude_from_board且非DNP。原生板级网表157元件/166网、逐焊盘和原生parity通过。
- 影响与根因：误导后续修复者给外置保险和源端子添加板上占位封装。
- 建议修复：为工具增加off-board识别及聚焦回归，仍保留真正板载缺失的检测；本报告人工解释，不改结果或忽略检查。
- 关闭标准：当前原始XML应不再误报F1/J6；删掉真正板载器件的mutation仍失败。
- 阶段：审计工具修复；不阻塞电气layout。状态：OPEN。

### S18 · P2 · corner_basis把INA REF1/REF2文字写反

- 对象/来源：gate_ab_verify.py/qualification.json；derived evidence。
- 证据：qualification.json文字为REF2=VA5;REF1=GND，实际新网表U2..4.7(REF1)=VA5、.3(REF2)=GND。对当前对称VA5/2公式数值无影响。
- 影响与根因：可能诱导后续错误改线；派生报告文字不能覆盖原生物理引脚证据。
- 建议修复：后续修正描述并加入实际pin7/pin3对应回归；无需为使文字“正确”而交换原理图参考引脚。
- 关闭标准：新派生证据文字与物理网表一致，原有数值回归保持通过。
- 阶段：审计工具修复；不阻塞电气layout。状态：OPEN。

### S19 · P1 · 继承忽略项及电流/间距规则需显式审核

- 对象/来源：project rules / PCB；ERC / DRC configuration。
- 证据：本轮ERC报告有4类ignored_checks，DRC有5类，逐项见报告第3节；exclusions为0并不等于没有忽略。当前POWER类间距0.8mm/线宽3mm是设计设定，不是10Arms温升或特定绝缘等级证据。
- 影响与根因：默认或继承规则可漏掉封装/工艺问题；3mm标称线宽不能替代铜厚、铺铜、过孔和接触电阻计算。
- 建议修复：按实际板厂能力、电压污染环境和额定电流审核有效规则、所有忽略类型，建立功率铜/模拟/门极/边缘/阻焊约束；不降低严重级别获取PASS。
- 关闭标准：规则及每项继承忽略有批准理由，关键封装类型/过滤器/庭院完成独立检查；热和间距计算可追溯。
- 阶段：布局冻结前审定；投板前全部闭合。状态：OPEN。

### S20 · P1 · 电流链采样窗口、抗混叠和复位时序未闭合

- 对象/来源：U2..4/U6/R40..42/C40..42/FPGA；current_adc / XDC。
- 证据：三路RC仅47ns/3.386MHz，20kHz衰减约0.0001515dB；ADC±5V量程、双DOUT及模式静态正确。项目没有本次可综合验证的伺服HDL/Vivado时序报告。来源[D2][D4]。
- 影响与根因：无法由20kHz PWM直接推出采样精度、闭环延迟和PWM边沿避让合格；修改共用RC也会改变OCP响应。
- 建议修复：定义采样率、PWM同步/禁采窗口、SCLK/CS边沿、BUSY握手、上电RESET及失效数据策略；评估INA共模恢复、ADC驱动/建立和线缆传播，再决定滤波。
- 关闭标准：提供完整时序预算与驱动/滤波依据，软件/HDL按接口合同实现；布局预留测量点，样机校准增益/偏置及PWM动态误差。
- 阶段：布局冻结前确定接口时序；样机验证。状态：OPEN。

### S21 · P1 · 25A外置保险尚未按现行10A目标完成配合

- 对象/来源：F1/holder/J3/源及线束；power_input / system。
- 证据：准确型号KLKD025.T及座LPSM0001Z已记录，外置身份正确；历史选择依据涉及15A/25A，不能直接作为当前母线电流/短路证明。源端保险不限制本地0.2304J标称电容能量。
- 影响与根因：相电流不等于母线电流；保险分断能力、I²t和动作时间未与源、线缆、MOS应力及启动冲击匹配。不能因此直接把保险改成10A。
- 建议修复：按实际母线电流、预期故障电流、线缆、环境和浪涌重做保险配合，必要时调整保险/限流/预充及系统接线要求；保持源端就近保护原则。
- 关闭标准：记录厂家曲线版本、源参数和配合计算，正常启动不误断、线缆故障能受控切除；局部桥臂保护另按S02/S04闭合。
- 阶段：正式输入功率布局前确定边界；功率上电前验证。状态：OPEN。

## 6. 修复顺序、验收与区域放行

| 顺序/任务 | 覆盖ID | 可审查交付物 | 验收门禁 |
|---|---|---|---|
| R1：ADC有效性硬件许可 | S01，关联S09 | 阈值/延迟角点计算、准确型号、局部电气变更、物理脚回归和更新BOM | 先用旧网表观察新规则失败；新网表/六检查/ERC通过；无效模拟供电不允许RUN_OK；动态证据不足仍明确开放 |
| R2：故障覆盖及源/回馈架构 | S02/S03/S04/S05/S21 | 现行工况、保护覆盖矩阵、限能/吸收与SOA预算、需新增器件/接口及空间 | 不能以熔断器或死区替代未覆盖路径；形成可约束功率布局的设计输入 |
| R3：电源、采样及驱动资格 | S06/S07/S08/S09/S20 | 三轨负载表、磁件/电容选型、bootstrap/死区/采样协议及适用模型 | 新电气图和参数计算互相对应，缺失厂商动态模型/台架项目继续分阶段开放 |
| R4：外部接口与机械/装配冻结 | S10/S11/S12/S13/S15 | AX7010电源/线缆合同、编码器边界、NTC对象、封装尺寸对照和装配属性 | 正式相关区域布局前不留影响接口/器件尺寸的未决项；实板验证计划明确 |
| R5：清理PCB遗留铜并受控开始layout | S14/S19 | 板快照、逐项旧铜处置及有效约束审定、区域放行记录 | 保留机械和正确连接；原生parity0，旧短路逐项关闭；新增布线后按阶段DRC，投板前未连接/DRC均0 |
| R6：审计/文档回归修复 | S16/S17/S18 | 注释规格统一、off-board工具回归、REF文字修正 | 无电气改线；真正缺板器件mutation仍失败；不改历史原始证据 |

**唯一建议下一任务：R1，修复并验证ADC欠压时的硬件禁止与锁存。** 本次不实施该修复。R2必须在正式功率铜布局前完成，不能因先修R1而默认功率部分已放行。

每个电气修复批次：保存原始快照，记录授权的网络变化，重新导出XML/板级网表，对比元件身份/物理脚/网名，运行六检查＋安全/OCP检查＋全严重级别ERC，逐页复看受影响区域。纯图面整理要求网络精确等价；真实电气修复要求差异仅为被批准项。新增关键约束要证明能拒绝旧缺陷。PCB同步是独立动作，不包含在原理图修复默认范围内。

不要求把普通未布线项在初次layout入口就降到0，但**当前17条跨网短路不是普通未连接项**，必须在继续正式新增布线前完成旧铜清理。最终投板门禁不能沿用这个阶段性例外。

### 样机阶段保留的验证项目

- 三电源域八组合、六上电/六掉电顺序，慢坡、快速棕断、短脉冲；测实际PG/POR/ARMED/RUN_OK与六路VGS。当前`power_domain_matrix.csv`只列静态目标，未做这些动态测量。
- 受控低能量验证采样有效性、ADC RESET/BUSY/SCLK时序、PWM边沿避让、共模恢复和校准；每路电流正负方向和阈值。
- 在已审定的限能条件下测OCP总链路、窄脉冲、CLEAR竞争、最大占空/自举、死区、开关节点和母线尖峰；不得先做无约束高能量短路。
- 实际电源回充/制动及断电工况、端子线缆/保险配合、最高环境下10Arms热稳态、编码器线缆/端接/ESD及NTC开短路。

本轮没有实物操作、厂商有源器件全链路仿真、Vivado实现时序、实际热模型或机械装配签核。对应资格仍开放，不能在下一轮以本报告的自动检查通过替代。

## 7. 图面、封装及证据索引

所有八页已查看本轮导出PNG；重点复核第2/4/5/6/8页电源、接地及局部回路。未发现新的孤立电源图例或子页端口只连电源图形的绕过；`check_power_wiring.py`同时通过。第5页较密集，后续可做可读性整理，但不得用移动符号来掩盖电气资格缺口。顶层页采用跨功能标签是允许的系统层次表达。

| 证据 | 用途 |
|---|---|
| `manifest.json`、`git_sha.log` | 源版本、原始命令/退出码及前后哈希 |
| `netlist.xml`、`board.net`、`bom.csv` | 本轮原生导出，不引用历史网表证明新PASS |
| `erc.json`、`drc.json` | 八页覆盖、全严重级别、继承忽略、实际违规及parity |
| `physical_pins.csv`、`component_inventory.csv`、`analysis.json` | 648节点、159对象、BOM/库一致性、短路旁路拓扑和公式 |
| `board_geometry.json`、`parity_audit.json` | 关键焊盘/钻孔和辅助工具原始误报 |
| `schematic.pdf`、`page-1..8.png/txt` | 本次完整图面及提取文本 |
| `qualification.json`、`spice/results.json`及6份deck/CSV/图 | Gate A/B物理合同/计算、独立DLL被动仿真及模型边界 |
| `power_domain_matrix.csv` | 三域八稳态目标；不是动态PASS |
| 各`*.log` | 完整检查/测试输出，包括跳过/失败原因 |
| `sources/manifest.json`及补充source JSON | 厂商下载URL、缓存身份与SHA256 |
| `final_verification.json`、`evidence_index.json` | 交付时源完整性、报告/CSV一致性及完整证据哈希 |

### 原厂资料及来源边界

TI/Infineon下列主要手册已在本轮重新下载并保存哈希；FD6288、Ohmite及Phoenix使用现有厂商PDF缓存并明确标识，不能宣称全部已核对最新版本。公开网页访问失败和本地工具跳过在证据记录保留；不以第三方摘要替代无法获取的原厂保证。

| ID | 资料与审查位置 |
|---|---|
| D1 | [TI TPS3808 Rev.N][D1]，p3..7：阈值、脚序、精度/迟滞与延迟 |
| D2 | [TI ADS8588S Rev.A][D2]，p3..7、37、接口时序及51..53：脚序、AVDD、串行配置、参考/去耦/布局 |
| D3 | [TI LM74502 Rev.A][D3]，p1、3..4：反接/反流边界、脚序、电压范围 |
| D4 | [TI INA241A Rev.D][D4]，Table5-1及增益/参考/动态章节：保留pin4、REF和共模 |
| D5 | [TI TLV9024 Rev.H][D5]，脚序、开漏输出及延迟测试条件 |
| D6 | [Fortior官方资料目录][D6]；本地`fd6288_v1_6.pdf` p4/6/8/10..14：典型应用、TSSOP20、时序条件。缓存来源保留，不冒充新下载 |
| D7 | [Infineon BSC040N10NS5][D7]：S/G/D、VDS、RDS、Qg及SOA/热条件 |
| D8 | [TI LM5164 Rev.D][D8]，p3、16..19：引脚、12V应用、LC与纹波网络 |
| D9 | [TI TPS6216x Rev.E][D9]，p4..5、应用/PG：固定5V选项、FB/VOS、工作范围 |
| D10 | [TI AM26LV32E Rev.E][D10]，p3..5：脚序、VCC/共模与温度范围 |
| D11 | [TI TPDxE05U06 Rev.O][D11]，p5..6：RVZ14映射与IO工作电压 |
| D12 | [TI SN74LVC1G74 Rev.G][D12]，pin/functions、异步清零和时序；另下载1G11/2G08/1G17/1G14手册核对门控 |
| D13 | [TI SN74LVC3G17 Rev.F][D13]，pin/functions、温度与开关条件 |
| D14 | [Coilcraft MSS1246T][D14]：68uH订货码、电流/温度及机械图 |
| D15 | [Würth 74438356022][D15]，003.002/2026-09-01，p1..2：L/DCR/额定电流/推荐焊盘及热条件 |
| D16 | [ALINX官方原理图目录][D16]及[官方J10手册表][D17]：V2图纸p5/15与活跃引脚对照。HTML本地下载403，网页已阅读；不宣称2022实板通断验证 |
| D18 | Phoenix 1714971/1714984厂商缓存绘图页：9.52mm、1.3mm；Ohmite厂商60-series缓存：650FPR005E及四端尺寸。当前厂商[端子产品页][D18]和[shunt产品入口][D19]用于来源追踪，样件/装配尚未验收 |

### 历史发现的本次状态

| 历史问题 | 本次判定 |
|---|---|
| D1..4符号/封装极性 | 已修复，K1/A2在新源/网表/焊盘一致 |
| U6串行模式13脚错误NC | 已修复，实际必需接地脚含BYTE_SEL均已接地 |
| INA241保留pin4悬空 | 已修复，三个pin4均接GND |
| C43..45两端GND、局部去耦/下拉缺失 | 已修复，本次可见连线及网表通过 |
| U19旧脚序/封装 | 已修复；当前新增审查关注电压适配，不重复报脚序错误 |
| 旧板F1/J3同步、安装孔 | 元件/焊盘同步与机械孔已修复；遗留铜短路和未连接仍未关闭 |
| ADC欠压、OCP动态、回馈、供电时序 | 仍开放；详见S01..S10 |
| NTC电机接口、J2真实DNP、派生REF文字 | 本轮明确列出S12/S15/S18，后续按证据修复 |

## 8. 审计完整性与交付限制

本次不修改原理图、PCB、符号/封装库、BOM、XDC或检查器；报告和CSV是新增文档，审计脚本及原始证据位于本地artifacts。未提交、推送、合并或更新旧release gate勾选。审计前已存在的项目设置修改和未跟踪文件均保留。

源文件完整性以`final_verification.json`和原始manifest对照为准。正式审计报告交付后，任何设计变更都使相应结果需要重新运行；不能把本次零ERC长期套用于后续修复版本。

[D1]: https://www.ti.com/lit/ds/symlink/tps3808.pdf
[D2]: https://www.ti.com/lit/ds/symlink/ads8588s.pdf
[D3]: https://www.ti.com/lit/ds/symlink/lm74502.pdf
[D4]: https://www.ti.com/lit/ds/symlink/ina241a.pdf
[D5]: https://www.ti.com/lit/ds/symlink/tlv9024.pdf
[D6]: https://www.fortiortech.com/en/download/2/20
[D7]: https://www.infineon.com/assets/row/public/documents/24/49/infineon-bsc040n10ns5-datasheet-en.pdf
[D8]: https://www.ti.com/lit/ds/symlink/lm5164.pdf
[D9]: https://www.ti.com/lit/ds/symlink/tps62163.pdf
[D10]: https://www.ti.com/lit/ds/symlink/am26lv32e.pdf
[D11]: https://www.ti.com/lit/ds/symlink/tpd6e05u06.pdf
[D12]: https://www.ti.com/lit/ds/symlink/sn74lvc1g74.pdf
[D13]: https://www.ti.com/lit/ds/symlink/sn74lvc3g17.pdf
[D14]: https://www.coilcraft.com/pdfs/mss1246t.pdf
[D15]: https://www.we-online.com/components/products/datasheet/74438356022.pdf
[D16]: https://github.com/alinxalinx/AX7010_2023.1/tree/master/Hardware/01_SCH
[D17]: https://ax7010-20231-v101.readthedocs.io/zh-cn/latest/AX7010UserManual_CN/AX7010UserManual.html
[D18]: https://www.phoenixcontact.com/en-sa/products/pcb-terminal-block-mkds-5-2-95-1714971
[D19]: https://www.ohmite.com/catalog/60-series/650FPR005E/

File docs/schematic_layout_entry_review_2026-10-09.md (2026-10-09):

# 原理图说明、电气仿真与 PCB layout 入口审查

后续更新：用户已要求在新分支修复。两项P0与图板一致性问题现已关闭，最新为ERC0/0、parity0、271DRC/478未连接。见[修复记录](layout_entry_repair_2026-10-09.md)。下文保留修复前审查与仿真边界，不代表当前仍有这两项接线缺陷。

本轮结论：**可以继续机械与功能分区预布局；正式器件布局/布线冻结 BLOCKED。** ERC 为零，但发现两项明确的器件应用缺陷。此轮保留硬件源文件，完成独立审查、局部 ngspice 仿真与说明文档，不把发现问题等同于已经修复。

## 本轮设计基准与证据

沿用现有架构与接口文档，用户于2026-10-09确认 **24–48V母线、10A连续相电流、20kHz PWM**。热耗暂按10A RMS计算，仍需确认RMS/峰值定义、环境温度、冷却条件、电机参数、峰值电流及回馈功率/能量。历史15A连续、25A/5s、55V上限、10–40kHz不构成本轮放行指标。48V以上仅用于过压风险计算。

审查基线是分支 `fix/ocp-latch-industrial-review` 的提交 `79dd6fc`，包括工作区已有 `.kicad_pro` 设置变化；不假定该设置与Git提交相同。KiCad10.0.3直接从8页原生层级导出。系统XML：159对象/180网；实际板级网表：157元件/179网（板外F1/J6不进入PCB）。[证据目录](reviews/layout_entry_2026-10-09/)保存鲜网表、原生ERC/DRC、检查日志、源文件哈希和模拟输出。源文件前后哈希一致，PCB仍为 `581f590151e439a771ab280e0449887680f917d3f7b9451c74a67d4b1b849eec`。

| 检查 | 本轮结果 | 含义 |
|---|---|---|
| 六项仓库源检查 | PASS | 原生语法、50mil网格、A4布局、可见连接、电源/GND可见接线、必需设计文件 |
| KiCad ERC | 0错误 / 0警告 / 0排除 | 不检查串行模式专用应用条件或符号端子语义 |
| 板级网表安全检查 | PASS，157/179 | 已有规则覆盖的供电、门控、下拉、采样连接 |
| OCP稳定数字状态 | 531场景 PASS | 不含模拟速度、短脉冲、竞争、功率MOSFET应力 |
| PCB检查工具回归 | 11项 PASS | 校验工具回归，不等于当前板合格 |
| 物理焊盘/网络一致性 | FAIL | PCB多F1、J3.1仍VIN_RAW而非VIN_FUSED |
| PCB约束检查 | PASS | 当前脚本覆盖的机械/网络约束，不替代原生DRC |
| KiCad DRC（重填铜，不保存板） | 271违规：220错误/51警告；466未连接 | 2交叉走线、17短路、113间距、88阻焊桥、8悬空线、43孤立铜 |
| 原生原理图一致性 | 3警告 | J3.1网络冲突、J1缺Board_Revision字段、PCB残留F1 |

DRC仍有五项继承忽略类型：missing_courtyard、track_not_centered_on_via、tuning_profile_track_geometries、footprint_filters_mismatch、footprint_type_mismatch。未新增忽略、降低严重度或删除连接。后续制造放行须复核这些配置。静态XML结构审计包含板外元件，不能代替实际板级网表的原生一致性结论。

## 八页原理图的功能与阅读说明

| 页/文件 | 功能与主要链路 | 布局与验证重点 |
|---|---|---|
| 顶层 ax7010_servo_reva | 七个子页层级端口互联；分开母线、三电源域、PWM、采样、保护、编码器 | 子页电源/GND端口和图形必须通过真实可见导线接元件，不允许旁边孤立图例代替连接 |
| power_input | 板外PSU J6→外部F1→J3 VIN_FUSED→LM74502/Q7/Q8→VBUS_PROT；R1/R2/R3/C5检测母线 | 外置熔断器需协调线缆/故障能量；D1是DNP；没有已合格的制动吸收器 |
| aux_power | LM5164将母线转12V；TPS62163固定5V；PG开漏并联为PWR_GOOD | 输入/开关回路、FB纹波网络、有效电容、磁件饱和和嵌套负载预算 |
| gate_inverter | FD6288三相驱动→六MOSFET→三相shunt→电机J4；自举VB/VS和栅源下拉 | D2..4物理极性P0；预充/刷新/死区；功率与栅极回路、SW铜面与采样隔离 |
| current_adc | 5mΩ Kelvin→INA241A2→47Ω/1nF→ADS8588S及窗口比较器 | U6串行模式接地P0；REF/REGCAP去耦；采样窗口；共用RC改变会同时影响OCP |
| ocp_latch | OCP、PG、双域监督→异步清锁存；EN低时CLEAR边沿重武装；ARMED门控PWM | 总关断时间、CLEAR竞争、欠压窗口、三域部分供电、配置期默认关断 |
| encoder | ABZ差分→TPD6E05U06/AM26LV32E→FPGA；共享5V经F2供编码器 | 端接DNP、屏蔽NC、ESD共模、PTC型号与短路拖垮模拟电源风险 |
| ax7010_interface | J1接已确认2022版J10；PWM/EN/CLEAR、ADC双DOUT、ABZ与诊断；J2 DNP | 实物逐针连续性、XDC/LVCMOS33、VIO预算与电缆回流；不能将J2当已实现并行ADC接口 |

VDRV_12V由母线产生，VA_5V来自12V级；VIO_3V3由AX7010提供。所有域共GND，但PCB回流不能任意混用。门驱/桥臂脉冲不得经过ADC参考或Kelvin支路。电源符号表达网络名称，局部真实接线与电容回路仍须在图面直接可读。接口细节沿用 [AX7010接口](ax7010_interface.md)，保护协议沿用 [OCP锁存说明](ocp_latch_review_2026-10-09.md)。

## 必须先关闭的明确问题

1. **P0：D2..D4极性编号冲突。** 自定义符号A1/K2，而指定官方D_SMA为K1/A2。图上12V→阳极、阴极→BST的方向正确，但按当前封装阴极带装配会反接。应统一真实端子与符号/封装编号，逐个确认实物阴极、焊盘、网表及装配图；不能靠旋转图形掩盖。D1/D_SMC有同类潜伏缺陷，目前DNP。详见 [功率级审查](power_stage_layout_review_2026-10-09.md)。
2. **P0：U6串行模式13脚错误NC。** 物理pins16..22、27..32（DB0..6、DB9..13、DB14/HBEN）按TI要求应接DGND/低电平。现有输出型引脚和NC标记使ERC无法发现。修复后须新增逐物理脚回归并重新导出/ERC。详见 [模拟与安全审查](analog_safety_layout_review_2026-10-09.md)。

这些结论来自物理端点与厂家应用条件比较，未通过降低ERC/DRC严重度消除。零ERC不能作为关闭证据。

## 已完成的局部电气仿真

本机KiCad附带 **ngspice-46 shared library**。工具先读取鲜XML的元件值并校验端点拓扑，再生成六份SPICE电路；DC/瞬态实际由ngspice求解。采用明确数值精度选项，结果与独立闭式计算交叉检查PASS。模拟方法参考 [ngspice官方共享库接口](https://ngspice.sourceforge.io/shared.html)。启动有找不到spinit提示，当前理想R/C源仿真不需要该文件；本轮未加载厂商IC模型。库哈希、日志、网表哈希在results.json中。

| 模型/工况 | 数值结果 | 解释及边界 |
|---|---|---|
| 母线分压DC，24..48V，1V步进 | ADC输入1.562604..3.125209V | 名义R值；未含漏电、ADC加载、温漂 |
| 分压戴维南等效RC，1V阶跃 | τ364.608us，fc436.51Hz | 归一化等效输出阶跃；不是输入母线过压保护仿真 |
| OCP分压DC，VA5=4.75..5.25V | 5V时低/高限0.294118/4.705882V，标称±22.0588A | 电流换算采用名义INA增益20和5mΩ；不是比较器/INA瞬态模型 |
| 静态角点枚举 | 20.743..23.402A | VA5±5%、分压±0.1%、shunt±1%；不含IC误差/温度/延迟，5%是探索工况不是批准电源公差 |
| R40/C40，理想1V阶跃 | τ47ns，fc3.386MHz；20kHz增益−0.0001515dB | 基本不衰减PWM基频；不能据此称抗混叠/电流保护合格 |
| R88/C92，理想3.3V GPIO阶跃 | τ1us | R87负载接理想源侧；没有GPIO输出阻抗、逻辑阈值或竞争模型 |
| C1+C2=200uF，48V初值，无吸收，注入1A | 1.4ms到55V，额外储能0.0721J | 无源钳位/ESR/ESL；55V为过压演示，不能作允许母线值 |

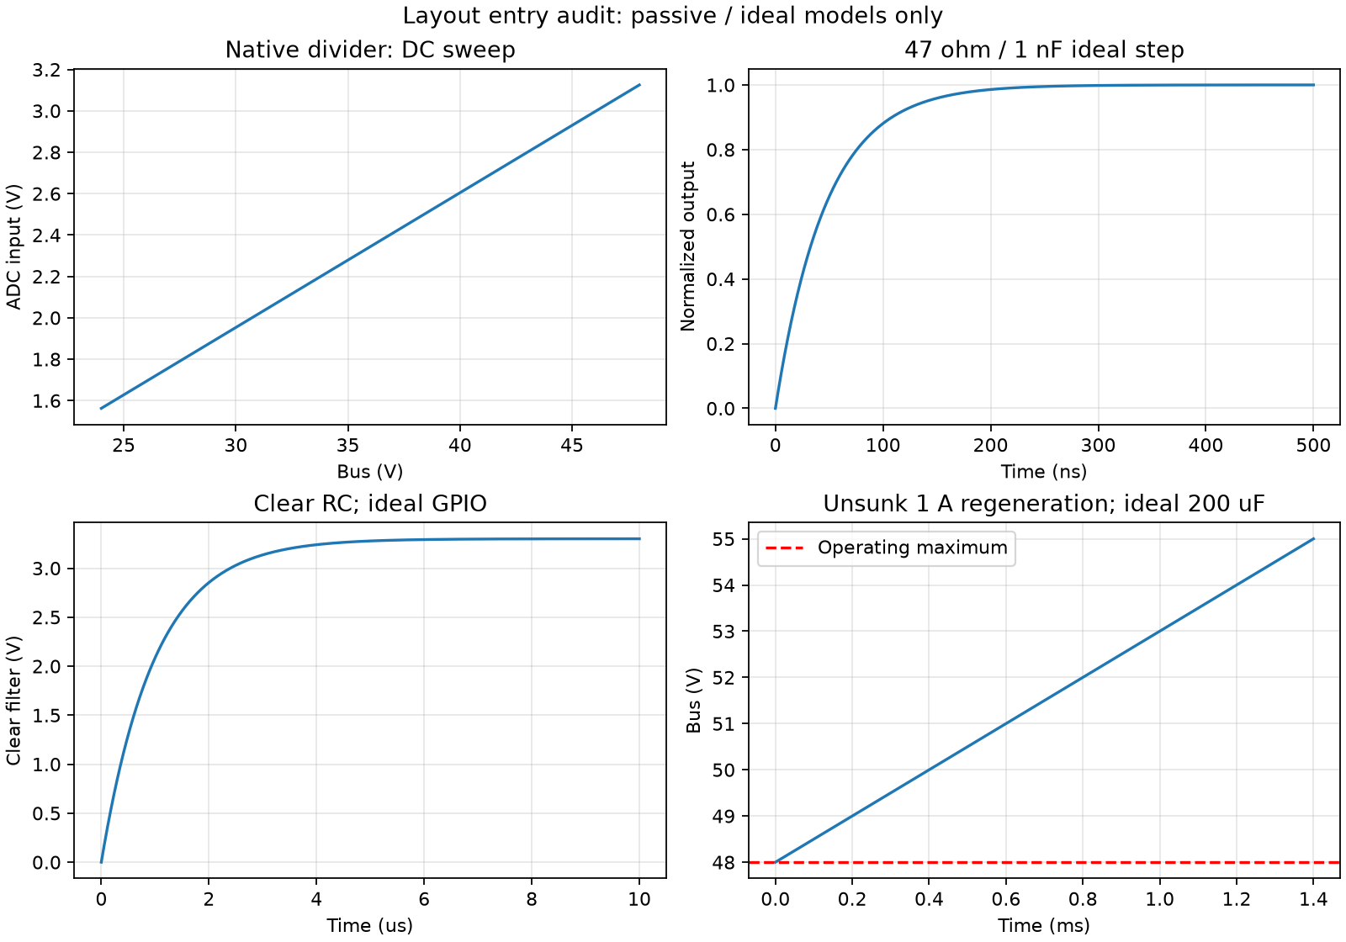
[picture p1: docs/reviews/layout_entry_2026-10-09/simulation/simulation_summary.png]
局部ngspice仿真


仿真工具与输出：[脚本](../tools/simulate_layout_entry.py)、[结果JSON](reviews/layout_entry_2026-10-09/simulation/results.json)、[电路/CSV/日志](reviews/layout_entry_2026-10-09/simulation/)。复现示例（先从当前原理图重新导出，不复用过期网表）：

```powershell
kicad-cli sch export netlist --format kicadxml --output artifacts/layout_netlist.xml hardware/ax7010_servo_reva.kicad_sch
python tools/simulate_layout_entry.py artifacts/layout_netlist.xml --ngspice-library D:/Software/KiCad/10.0/bin/ngspice.dll --output artifacts/layout_simulation
```

独立审查已重跑同一工具，数值结果一致；另用网表副本移除R40.2，验证脚本在加载模拟器前拒绝错误拓扑（[拒绝测试](reviews/layout_entry_2026-10-09/simulation_guard_test.json)）。文档本地链接、证据哈希及图像布局已检查。

这些结果只关闭“名义被动网络计算有可重复证据”这一项。没有电机/负载/源模型、厂商MOSFET/驱动/INA/ADC/比较器模型或PCB寄生，因此没有完整三相逆变器、电源启动环路、总OCP速度、死区直通、ADC建立时间、热或EMC仿真合格结论。

## 正式布局的关闭顺序与交付要求

| 阶段 | 要求 | 当前状态 |
|---|---|---|
| 原理图修复 | 两项P0和D1潜伏问题；补机器可查回归，BOM/图纸/网表统一 | OPEN |
| 电气规格冻结 | RMS/峰值、环境、冷却、源吸收与回馈能量；OCP阈值与软件限流 | OPEN；10A连续已确认 |
| 元件/供电资格 | 完整MPN、封装方向、C有效容量、L饱和、DC-link纹波、F2、VIO预算、ADC欠压策略 | OPEN；LM5164主要元件已与TI参考拓扑核对 |
| 受控预布局 | 保留130×95mm轮廓及H1..4中心；功能分区、连接器/散热空间、测点规划 | 可继续；不代表电气布局冻结 |
| PCB同步 | 备份板，关闭电气/封装缺陷，再移除板外F1、改J3网络、协调J1字段；核查物理焊盘/UUID/DNP | OPEN；当前parity FAIL |
| 关键布局/布线 | 先DC-link/半桥/栅回路，再Kelvin/ADC参考/OCP，再数字与编码器；叠层铜厚和热模型确定线宽/过孔 | OPEN；禁止以当前20条旧线为可用成品 |
| 低能量验证 | 电源独立启停、所有VGS/死区、bootstrap、短路/OCP、CLEAR竞争、编码器负载、采样共模恢复 | OPEN；先限能，不直接24/48V满电流 |
| 冻结/制造 | 最新ERC/DRC/parity、0未连接、已审包封/装配方向、10A热浸/切换过冲、全部release gates | BLOCKED |

建议在板上预留VDRV、VA5、VIO、POR_N、PWR_GOOD、OCP_N、ARMED、RUN_OK、CLEAR_FILT、三路电流输出、VBUS_ADC及六路栅源测量位置。高侧VGS/自举使用合格差分测量方式；测点与探头空间不能扩大高di/dt环路。

总关断预算必须覆盖INA→共用RC→比较器/开漏→锁存/门控→FD6288→MOSFET栅放电，不能只引用32ns数字链。TPS3808G50最坏下降阈值可能低于ADC的4.75V最小供电；PWR_READY不等于ADC有效。三域独立存在/消失、FPGA配置/高阻和残压需验证。其余逐项证据与厂商链接见两份专项审查，统一关闭清单仍在 [release_gates.md](release_gates.md)，上电步骤仍在 [bringup.md](bringup.md)。

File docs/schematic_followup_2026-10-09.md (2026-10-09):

# 后续修复与图板同步审查

## 已完成的确定性修复

U19 TPD6E05U06RVZR 原有符号错误地只定义了 7 个引脚。已按 TI RVZ 数据手册修正为完整 14 引脚：六个通道使用 14/13/12/11/9/8，接地使用 5/10，NC 为 1/2/3/4/6/7。两个接地脚在原理图同节点显式堆叠，不使用隐式全局电源网络。补齐 `Package_SON:Texas_R-PUSON-N14` 封装并同步库、嵌入符号和 BOM。

新增真实引脚映射回归检查：先在旧网表观察到失败，修复后通过。网表现为 **137 个器件 / 169 条网络**；新增 6 条网络均为 U19 明确 NC 的引脚网络。旧审查中的 163 是本次修复前的历史值。

## 不能直接沿用的 PCB 内容

当前 PCB 有 32 个封装，原理图有 137 个器件：

- PCB 缺少 115 个当前位号。
- 22 个同位号器件的封装标识均不匹配，旧板使用 `fpga-servo:*` 简化封装。
- PCB 独有 CBUS1/CBUS2、RSHU/RSHV/RSHW、U14 等旧位号；H1..H4 为机械孔，不能当作普通多余电气器件直接删除。
- 已移除的本地 LDO、旧并行信号、PGND/Kelvin 伪网络仍在旧板中。
- 老板 20 段走线及铜区存在 54 项短路和 2 项交叉，不能凭原坐标保留就宣称连接有效。
- 全部 DRC 分类：tracks_crossing=2、shorting_items=54、clearance=24、solder_mask_bridge=118、track_dangling=3、silk_edge_clearance=7、lib_footprint_issues=32、silk_overlap=6、silk_over_copper=112；未连接 129 项。

同步应先保存旧板快照，再用真实库封装和当前网表逐焊盘重建一致性；旧铜只能在端点、净距和网络均重新验证后保留。不能通过删除线路或取消未连接检查制造“DRC 清零”。差异详情：`artifacts/pcb_sync_audit.json`。

## 新确认的功率器件问题

- 现用 GMSTBA 2.5/3-G-7.62 型接线端子的制造商额定电流为 **12A**，低于项目 15A 连续相电流和 25A 峰值目标。更换功率端子会改变间距、孔径和板边空间，需先冻结替代型号再摆放。
- 原描述 BVB-I-R005 的制造商额定为 **3W（70°C条件）/2W（高温条件）**，并非项目要求的 >=5W。5mΩ 在 25A 时耗散 3.125W，不能把此型号当作 5W 分流器闭合。三个分流器封装仍未分配，不能用通用封装冒充。
- LM74502 无反向电流阻断，OV 仅检测输入侧，不能单独处理母线再生能量。其 65V 输入限制与 55V 连续上限之间的浪涌裕量必须进行最坏钳位分析。

来源：

- [TI TPD6E05U06 数据手册](https://www.ti.com/lit/ds/symlink/tpd6e05u06.pdf)
- [Phoenix Contact 1766246](https://www.phoenixcontact.com/en-us/products/pcb-header-gmstba-25-3-g-762-1766246)
- [Isabellenhuette BVB 数据手册](https://www.isabellenhuette.com/hubfs/Files/Data-sheets/BVB.pdf)
- [TI LM74502 数据手册](https://www.ti.com/lit/ds/symlink/lm74502.pdf)

## 下一步电路方案

优先闭合独立 OCP 硬件锁存，具体可审阅方案见 `docs/superpowers/specs/2026-10-09-ocp-latch-design.md`。

母线保护有两个分支：可吸收再生的电源允许保留双向回流但须验证源端吸能与输入保护；普通单向电源需要反向阻断和独立制动斩波器/外接制动电阻。TVS 只承担规定浪涌，不能承担未限定的制动能量。

制动电阻按 `R <= V_clamp^2 / P_regen_peak` 选吸收功率，再验脉冲能量、平均功率和失效状态。电阻/斩波器的最终 MPN 依赖最大制动能量、周期、环境温度及实际电源容差；在这些参数未知时不能声称闭合热设计。

AX7010 实物版本和制动工况已向用户询问。机械板框保留现状作为约束，功率端子变化需要验证可容纳性。最终 ERC、图板逐焊盘一致性、布局检查、DRC 和 bench 门槛分别验收，不能互相替代。

本轮尚未改变 OCP 恢复策略、母线功率通路或 PCB；DRC 基线仍未闭合。

## 本文之后的锁存实施

以上 137/169 和未改变 OCP 的表述为 U19 修复阶段快照。用户确认后已新增 U20..U26 硬件锁存和整形，当前为 158 器件 / 183 网络。最新状态以 `ocp_latch_review_2026-10-09.md` 与 `release_gates.md` 为准，PCB 仍未同步。

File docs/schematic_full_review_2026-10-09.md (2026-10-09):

# 全工程原理图表达优化与复查

日期：2026-10-09。分支：`fix/ocp-latch-industrial-review`。原生 KiCad 10.0.3，A4 横向，一张总览和七张子页。此记录接续已有 Gate Driver / Current Sense 重排，保留并提交本次任务开始时已有的相关原理图修改。

## 最终图面

[八页原理图 PDF](reviews/schematic_full_review_2026-10-09.pdf)。每页标题栏显示 `Id: 1/8` 至 `Id: 8/8`，总览功能框补充对应页码导航。

- System：统一短线标签朝向和外侧留白；两段靠标签连接的 GND 短线补上可见导线，消除重复文字而保持原有网络。
- DC Input：将 VBUS_DIV_MID 标签引到分压电阻上方，缩短页脚，避开标题栏。
- AX7010 Interface：左侧层次端口向内移动并调整字体，改善页框余量和密集信号文字。
- Auxiliary Power：减少与层次端口相邻的重复标签；将 PWR_GOOD 引到 U13 上方的空白区。
- Current Sense 与 Gate Driver：保留上一轮统一的三相/三通道排列、本地自举/栅极/滤波导线；普通电阻隐藏数字引脚名称以减少拥挤，物理编号和网络映射保留。
- Encoder：缩短侵入标题栏的注释；U19 的 5、10 接地物理脚分开绘制并用原生导线相连，库与嵌入定义同步。
- OCP Latch：移开与顶部电源文字拥挤的 CT 注释，页脚保持在安全区域。

已逐页查看最终渲染，以及总览端口、输入分压、接口端口、PGOOD、ESD、复位监控、ADC 引脚、栅极回路和 OCP 页脚放大图。MOSFET 同功能封装叠放焊盘保留原符号表达及映射；此审查关注功能可读性和连接保持。

## 页码与图标

KiCad 10 工程管理器的绿色勾表示 Git 已跟踪文件没有修改，红色空心圈表示未提交修改；这不是电气/ERC 状态。提交后可以刷新工程管理器确认图标。

源文件的根页实例为 1，各子页实例为 2–8，页数和顺序完整。本次原生全层次 PDF 八页页码全部正确。没有检查或修改用户正在运行的编辑器本地显示偏好，因此不能宣称编辑器的显示问题已复现或修复。

从 `.kicad_pro` 打开工程根图，再通过层次导航进入子页。编辑器内页框/标题栏不可见时，检查 Appearance 面板的 Drawing Sheet 可见性；层次树不可见时检查 View → Panels → Hierarchy Navigator。绘图导出时启用 Plot drawing sheet。若仍有问题，应根据实际 UI 区分页框显示、层次导航、缩放或打开上下文，不应盲目重写已正确的页码。

官方说明：[Project Manager Git integration](https://docs.kicad.org/10.0/en/kicad/kicad.html)、[Schematic hierarchy / appearance / plotting](https://docs.kicad.org/10.0/en/eeschema/eeschema.html)。

## 新鲜验证

- 原生 XML 前后：159 元件、180 网络、648 项物理引脚网络归属，身份/数值/封装/网名/每项 ref-pin 精确一致。
- 面向 PCB 的原生网表：157 元件、179 网络；系统 BOM 159 元件，已重新导出。
- 原生 ERC：0 错误、0 警告、0 排除；修改前后 ignored_checks 一致，未降低严重级别。继承的四项 ignored checks 为 single_global_label、four_way_junction、simulation_model_issue、footprint_filter；零违规仅指当前策略下的结果。
- 五项仓库回归全部通过：check_native_schematic、check_kicad_grid、check_schematic_layout、check_schematic_connectivity、check_design。
- check_netlist_safety 通过；check_ocp_behavior 通过 531 个稳态数字场景。
- 项目符号库所有物理脚号、脚名、电气类型和形状保持一致；U19 仅修改 pin 10 图形位置，新增导线由网表精确比较验证。
- PCB SHA-256 未变：`581f590151e439a771ab280e0449887680f917d3f7b9451c74a67d4b1b849eec`。

机器证据：[视觉记录](../.pcba-workflow/schematic-visual-audit.json)、[源文件/网表/PDF/ERC 哈希和页码证明](../.pcba-workflow/schematic-presentation-proof.json)。基线快照、网表、ERC 及 PNG 位于本地忽略目录 `artifacts/schematic_full_review/`；最终 PDF 已纳入 Git，可远端审阅。

## Skill 沉淀

采用项目本地 [schematic-humanizer](../.agents/skills/schematic-humanizer/SKILL.md)，新增 [配线与页码实践](../.agents/skills/schematic-humanizer/references/practical-wiring-and-pages.md)，覆盖重复通道节距、局部导线与标签边界、近邻线岛反例、文字完整范围、页码与 Git 状态诊断。[验证记录](schematic_humanizer_skill_validation_2026-10-09.md)。

参考 [TI TIDA-00913 原理图](https://www.ti.com/lit/pdf/TIDROJ7) 的功能分组画法；没有移植其参数。Skill 来源及原许可证保留：[upstream](https://github.com/Keitark/pcba-design-skills/blob/main/.agents/skills/schematic-humanizer/SKILL.md)。

本次不改变电气方案，不执行 PCB 同步或布线，未运行新的 PCB DRC。已有 PCB 外置熔断器同步差异、OCP 模拟时序、再生能量、热设计和实物验证仍按 [release_gates.md](release_gates.md) 保持开放；本次通过不等于制造发布。

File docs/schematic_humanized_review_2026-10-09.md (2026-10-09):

# Gate Driver / Current Sense 原理图重排复查

日期：2026-10-09。分支：`fix/ocp-latch-industrial-review`。

本轮修改原生 `hardware/gate_inverter.kicad_sch`、`hardware/current_adc.kicad_sch` 和项目符号库。保留已有未提交工作，不修改 PCB。

## 网上参考与 Skill

- [TI TIDA-00913 原理图](https://www.ti.com/lit/pdf/TIDROJ7)：参考其重复三相功能块、局部去耦和清晰电源/地表达。只借鉴画法，没有移植其电路参数。
- [KiCad KLC S4.2](https://klc.kicad.org/symbol/s4/s4.2/)：按逻辑功能分组引脚。
- [schematic-humanizer](https://github.com/Keitark/pcba-design-skills/blob/main/.agents/skills/schematic-humanizer/SKILL.md)：已安装到 `.agents/skills/schematic-humanizer/`，采用其原始快照、局部完整连线、放大审图和精确网表比对流程。

## 图面调整

Gate Driver：PWM 互锁三路纵向对齐；FD6288T 输入在左、驱动输出在右；U/V/W 三相功率级采用相同方向与间距。各相自举、栅极电阻、栅源下拉、MOSFET 和四端分流电阻在块内直接连接，长距离驱动信号使用匹配标签。修正标签压到下拉电阻、栅极电阻字段及开关节点附近文字拥挤。

Current Sense：三个 INA241 通道统一排列，输出电阻与滤波电容直接连接。窗口比较器上下分组，阈值电阻相邻放置，移开压到电阻的阈值标签。ADS8588S 按模拟输入在左、数字接口在右、电源在上、地与接地配置脚在下重画符号；参考电容贴近对应引脚，REFCAPA/B 保留两个独立物理引脚并分开显示。

电源箭头和地标记是项目库中的图形标记（可见连接点为被动引脚），配合明确的本地网络标签；它们不引入隐含全局电源合并，且不进入 BOM/PCB。跨页仍保留当前层次端口，本轮没有执行全工程 global label 迁移。

## 验证结果

- KiCad 10.0.3 原生 XML 网表：前后均为 **159 元件 / 180 网络 / 648 项引脚网络归属**，元件身份、数值、封装、网名与每项 ref/pin 归属精确一致。
- 面向 PCB 的原生网表：**157 元件 / 179 网络**。与 XML 的统计口径不同，系统包含外置连接对象。
- 修改前和修改后的原生 ERC：**0 错误 / 0 警告**；忽略检查列表一致，没有新增排除或降低严重级别。
- 五项仓库检查全部通过：native schematic、grid、schematic layout、schematic connectivity、design。
- 原生网表安全检查通过；OCP 稳态数字行为 **531 场景通过**。
- 两页功能块物理导线检查通过：Gate Driver 82 个块内网络组、157 个已连接物理引脚；Current Sense 66 个组、159 个引脚。该检查不通过标签合并局部导线岛，确认附近无源器件实际接入所属局部电路。
- 原元件属性、实例 UUID、引脚 UUID、DNP/板载标记保持一致；符号物理引脚编号、名称、电气类型和形状不变；修改符号的嵌入定义与项目库定义一致。
- PCB SHA-256 保持 `581f590151e439a771ab280e0449887680f917d3f7b9451c74a67d4b1b849eec`。

## 阅读与证据

- 两页阅读 PDF：`artifacts/schematic_humanized/Gate_Driver_Current_Sense_review.pdf`
- 全八页 PDF：`artifacts/schematic_humanized/final.pdf`
- 修改前 PDF/原生快照：`artifacts/schematic_humanized/before.pdf`、`before/`、`before_project/`
- 精确比对输入：`before.xml`、`final.xml`；ERC：`before_erc.json`、`final_erc.json`
- 属性/符号保护证明：`presentation_proof.json`；局部导线证明：`local_wiring_proof.json`
- 视觉记录及证据哈希：`.pcba-workflow/schematic-visual-audit.json`

以上证据位于本地忽略的 `artifacts/`，并非已提交到 Git。渲染全部八页并检查两页的七处密集区域；两页目标区域通过本轮视觉检查，美观程度仍供用户复核。其他未修改页面已有的重复文字、局部标签拥挤及页脚触及标题栏等问题在视觉 JSON 中记录，全工程视觉验收尚未关闭。

本轮只调整表达与图形，不代表新增电气设计批准。OCP 时序、功率/热设计、封装和实际 AX7010 接口验证继续遵循 `docs/release_gates.md`。未运行 PCB 布局、布线或制造发布。

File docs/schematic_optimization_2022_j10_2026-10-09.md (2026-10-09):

# 原理图优化 — AX7010 2022 / J10 与外置保险

用户确认 ALINX AX7010 2022 版、J10，并授权按推荐方案选保险；本轮仅修改原理图、检查、BOM 和说明，不同步或布局 PCB。保留分支 `fix/ocp-latch-industrial-review` 及所有已有未提交文件。

## 接口核验

对照 [ALINX 官方原理图目录](https://github.com/alinxalinx/AX7010_2023.1/tree/master/Hardware/01_SCH) 中 AX7010/AX7020 V2.0 文件第 5、15 页，视觉核对 J10 和 IO1 Bank 管脚。公开图纸标题栏日期为 2018-10-08，并非宣称已取得 2022 专用图纸。2022 实板身份来自用户确认，实物逐针通断和 Bank 电压仍需验证。

现有映射无需修改：1/37/38 地、2 为 5V 且本板 NC、39/40 为 VIO 3.3V，3..36 的 34 个信号脚映射与公开图一致。增加 J1 Board_Revision/Board_Connector 属性与活跃信号/供电脚安全回归，接口文档与 XDC 注释同步更新。辅助和 ENC_FAULT_N 等当前 NC 信号不因 XDC 预留而变成已连线。

## 保险选择与连接

推荐外置 **Littelfuse KLKD025.T**：25A、600VDC、10x38mm 熔断器；配 **LPSM0001Z** 单极非指示导轨座。位于电源正极靠近源端，保护到伺服板的线束；不能将未保护的长线先接板再在远端加保险。

厂家依据：[KLKD 数据手册](https://www.littelfuse.com/assetdocs/klkd-datasheet?assetguid=7b52eebb-c7cc-43df-a8da-9682a338e0f6)，2025-05-29，第 2 页额定、第 3 页订货、第 4 页电气数据和后续曲线；[Littelfuse 座产品目录](https://www.littelfuse.com/assetdocs/powr-gard-catalog?assetguid=d4b3148c-7de4-4106-be83-cebe03318781)，LPSM 系列 30A / 600VAC/DC，非指示单极 LPSM0001Z。所选 DC 耐压覆盖 55V 母线目标。应采用厂家规定装配扭矩、导线范围及环境降额。更高的额定电压不免除实际直流分断条件审核。

选择外置的工程原因是可维修、避免较大发热/夹持载荷占用 130x95mm 功率板、可在源端保护线束，并避开原未选型 2920 占位封装。25A 是当前设计初选，依据是既有 15A 连续/25A 短峰值目标；相电流不能直接等同于 DC 输入电流，不能声称已完成保险配合。

原理图明确 `J6.1 (PSU+) -> F1.1/2 -> VIN_FUSED -> J3.1 -> Q7/U18`，J6.2/J3.2 为 GND。J6 是外部电源接线边界，不是新增板载连接器，也不是已选定电源采购型号。F1/J6 均 `on_board no`、`in_pos_files no`，无 PCB 封装，保留在系统 BOM；F1 不是 DNP。F1 的 Holder_MPN 和 BOM 状态明确要求 LPSM0001Z，采购系统件时必须配齐此座。

不能将外置保险误解成完整功率保护：本地 DC-link 电容的放电故障电流不经过源端 F1；MOSFET/驱动/OCP 的动态保护仍必须独立工作。母线两个 100uF 电容仅其标称电容在 48V 已储能 0.2304J，在 55V 为 0.3025J；实际还含其他电容、容差及供电能量。输入浪涌、源限流、线束电流及环境降额、保险 I²t 和预期短路电流/时间常数要实测并对照厂家曲线。F1 不提供再生耗能或过压钳位；D1 仍 DNP，LM74502 OV 接低的现状保留为未关闭门禁。

## 修改和验证

原始快照与本轮证据：`artifacts/schematic_opt_2022/`；修改前硬件文件在 `before/`。保险及外部源端子在完整系统图中仍然连接，但 KiCad PCB 网表原生省略 off-board 对象。

- 系统图 / BOM：159 个对象（157 板载 + F1/J6 外部对象）。原 158 中的 F1 改为外部，新增 J6；不是删除保护电路。
- 新鲜 PCB 网表：157 元件 / 179 网络。外部 VIN_RAW 不进入板级网表，J3.1 现在直接为 VIN_FUSED。
- ERC：0 错误 / 0 警告 / 0 排除，未降低严重级别或增加忽略项。
- 原生结构、50mil 网格、A4 布局、层级连接、工程/BOM、安全网表、531 项 OCP 稳态场景及 11 项既有 PCB 检查器回归通过。
- 外部 F1 属性与 J3 输入连接的新增规则，已在旧设计上先观察失败，再验证新设计通过；没有以更新元件计数替代连接检查。
- 电源页 PDF/PNG 已渲染并视觉检查，清除了 Datasheet URL 覆盖接线的问题，端子/源侧导线移入边框。

PCB 文件 SHA256 与修改前相同。只读逐焊盘审计按预期失败：旧板额外 F1 一个、J3.1 网络不一致一个。此前 162 封装、271 DRC / 466 未连接 / parity 0 是旧同步阶段记录，不代表当前图板一致。未运行 PCB 布局布线、未发布制造资料。现有 CI 的图板一致性门禁也会保持失败直到用户允许后续同步，未屏蔽它。

## 后续原理图/样机门禁

已关闭接口身份和保险方案选择，未关闭实物逐针验证、VIO 最低释放条件、独立供电/反灌、OCP 脉冲/时序、辅助稳压器极限计算、FD6288 应用核验、母线浪涌/再生及温升。ERC 和数字回归不能代替这些证据，见 `docs/release_gates.md`。当前交付是经检查的这轮原理图优化，不能标为全部电气设计或制造资格已完成。

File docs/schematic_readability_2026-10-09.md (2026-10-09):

# 原理图连续电路与可读性整理

日期：2026-10-09。工作分支：`fix/ocp-latch-industrial-review`。

本轮处理元件散落、过度依赖标签和部分文字遮挡线路的问题。只整理原理图的排布、连线表达和注释，不改变电气设计，也不进行 PCB layout。

## 页面调整

| 页面 | 调整内容 |
| --- | --- |
| Auxiliary Power | 连出 U12 的输入电容、RON 电阻、bootstrap、电感、输出电容、反馈分压和纹波注入；连出 U13 的输入、输出 LC 和 VOS 回授；两路 PG 输出显式相连。 |
| AX7010 Interface | R80–R86 分别从 J1 的六路 PWM 和 GATE_EN 引出下拉支路，共用可见的 GND 回路；将未使用的 J2 移到独立区域。保留 AX7010 2022 / J10 标识和 pin 2 NC。 |
| Current Sense / OCP / ADC | 三路 INA241、输出 RC 与 ADC 电流输入直接连线；窗口比较器分为上下两组，阈值分压与参考母线直接相连；连接开漏故障汇流线和 R54；ADC 参考电容直接接到相应引脚；去耦银行移到标题栏以外。 |
| Gate Driver / Inverter | 补出六个 RGS 到对应 MOSFET 栅极节点的线路；U1 的 C69/C46 接入实际供电；R55 接入 PWR_GOOD/VIO 端口；六个输入下拉与四个逻辑去耦电容分别整理成共地/共电源母线组。隐藏遮挡线路的数据手册字段。 |
| Differential ABZ Encoder | J5、三组终端电阻、U19 ESD 分支与 U7 接收器形成连续差分通路；连出编码器供电保险和接收器电源去耦。J5 镜像、U19 旋转仅用于图面表达，物理引脚号不变。 |
| OCP Hardware Latch | 连出清故障 RC 滤波、Schmitt 缓冲、使能反相、锁存、下拉和 ARMED 测试点；两个 supervisor 共用 POR_N，经过 U26 接入保护逻辑；对应去耦电容就近绘制在各 IC 电源旁。 |

顶层与 DC Input 页原有主要电路已经连续绘制，本轮保持这两张源文件不变。所有子图仍使用原有层级端口。电源/地和部分跨功能区信号仍保留标签，例如驱动输入偏置组到 U1 的 HIN/LIN 链路，避免长线穿过其他功能块。

## 验证结果

- 新导出的前后网表：644 个引脚的网络名逐一比对，差异为 0。
- 系统 BOM：159 项；板载网表：157 元件、179 网络。外置 F1/J6 的处理保持不变。
- 所有器件的位号、UUID、引脚 UUID、属性值、封装及 BOM/on-board/DNP 状态一致。
- `check_native_schematic.py`、`check_kicad_grid.py`、`check_schematic_layout.py`、`check_schematic_connectivity.py`、`check_design.py` 全部通过。
- `check_netlist_safety.py` 通过；`check_ocp_behavior.py` 的 531 项稳态场景通过。
- KiCad 10.0.3 原生 ERC，`--severity-all --exit-code-violations`：0 错误、0 警告、0 排除违规。工程规则文件逐字节不变。
- BOM、项目符号库与 PCB 均逐字节不变。PCB SHA-256：`581f590151e439a771ab280e0449887680f917d3f7b9451c74a67d4b1b849eec`。
- 导出并逐页查看 8 页 PDF；`git diff --check` 通过。

本地检查证据保存在 `artifacts/schematic_readability/`：`before/` 源文件快照、`before.net`、`after.net`、`before.pdf`、`after.pdf`、`erc.json`、`verification.json` 和逐页 PNG。该目录按仓库规则不纳入 Git。

## 交付边界

这是保持电气网表不变的原理图表达整理。未执行 PCB 同步、布局、布线或制造导出，因此没有新增 DRC 通过结论。原有 OCP 动态时序、浪涌/再生、电流热额定值和 PCB 制造验收要求仍以 `docs/release_gates.md` 为准。

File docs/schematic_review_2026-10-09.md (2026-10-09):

# 原理图优化与 layout 准入审查（2026-10-09）

## 实测结论

KiCad 10.0.3 对当前原生七页层级原理图执行 `sch erc --severity-all --exit-code-violations`，结果为 **0 错误、0 警告、0 豁免项**。未新增忽略规则或 ERC 排除项。网表为 **137 个功能器件 / 163 条网络**；包含显式未连接引脚网络，此数量用于防止导出不完整，不能单独证明电气功能。

五项仓库检查和新增网表安全检查均通过。当前 PCB 未修改，实测 DRC 仍有 **358 项违规、129 项未连接**，32 个封装与 137 个原理图器件尚未恢复一致。

## 本轮修复

1. 修复迁移遗留的层级实例根 UUID：原理图顶层 UUID 与器件实例路径不一致，曾导致导出仅有 79 条网络、ERC 产生 9 项悬空导线；修复后真实网络完整恢复。新增实例根一致性检查。
2. 将项目相对路径 `sym-lib-table` 纳入设计源，消除本机缺少全局映射产生的 130 项符号库警告。CI 使用空全局符号表，验证项目自身能解析库。
3. R80..R86：六路原始 PWM 和 GATE_EN 各加 10k 下拉，限定 FPGA 配置期间高阻输入的默认状态。R56..R61 继续下拉门控后的 FD6288 输入。
4. C80..C83：U8/U9/U10/U11 各加 100nF 本地去耦。C84/C85：U15/U16 各加 100nF 本地去耦。
5. 修复 C43/C44/C45 两端均接 GND 的功能错误，改为 VA_5V–GND；同时移动电容、压缩 INA 符号高度并同步项目库，减少相邻电源标注重叠。
6. 缩短可见器件值，详细规格保留在隐藏 Description 字段；主要 IC/MOSFET/电感记录 MPN。BOM 按实际 137 个位号重新生成，删除旧缓冲器、LDO、锁存器等不存在的项目。
7. D1、R32、RT1..RT3 设为实际 DNP 装配状态，避免仅在文本中写 DNP。
8. 网表回归检查覆盖输入下拉、去耦、栅极串阻/下拉、INA–ADC 采样路径、RUN_OK 扇出，以及双端元件被同网旁路的问题。BOM 检查覆盖位号、器件值、封装、MPN 和 DNP 一致性。

## 设计依据

- [TI SN74LVC1G11 数据手册](https://www.ti.com/lit/ds/symlink/sn74lvc1g11.pdf)：逻辑输入不得悬浮。
- [TI SN74LVC2G08 数据手册](https://www.ti.com/lit/ds/symlink/sn74lvc2g08.pdf)：每个 VCC 配本地旁路，单电源推荐 0.1uF。
- [TI TLV9024 数据手册](https://www.ti.com/lit/ds/symlink/tlv9024.pdf)：每颗比较器电源直接以低 ESR 0.1uF 旁路至地。

这些资料支持本轮偏置和去耦修改，不代表已完成所有器件的逐脚/温度/容差/封装认证。

## layout 准入边界

当前可开展封装核对、图板同步和初步分区摆放。**尚不能宣称达到工业级或冻结最终布局**，必须继续关闭：

- **故障恢复策略**：当前 OCP 是组合关断，故障解除且 GATE_EN 仍高时会自动恢复 PWM。FAULT_CLEAR 尚无硬件消费者。需确定并实现硬件锁存/手动重新使能策略。
- **上电及失电安全**：配置期下拉不等同于安全认证。需验证 AX7010 VIO、VA_5V、VDRV_12V 不同上电顺序、缺电和拔线时的实际门极波形及反向灌电流。
- **母线能量与浪涌**：D1 默认不装，LM74502 OV 未启用；需确定上游保护、浪涌钳位和再生能量吸收方案。
- **物理接口及功率封装**：真实 AX7010 版本和逐脚核对、四端分流器、接线端子、保险器件的确切 MPN/载流/封装必须冻结。已填 IC 订货号仍需核对制造商封装图。
- **功率验证**：OCP 阈值容差、故障关断延迟、bootstrap、死区、开关过冲、EMC 和目标电流热验证仍需计算/样机证据。

现有原理图没有本地 3.3V LDO或独立数字缓冲阵列；VIO_3V3 来自 AX7010，供安全逻辑、编码器接收器及 ADC DVDD。接口表中 J2 的并行/辅助信号只是预留分配，当前为 NoConn。相关文档已更正。

## 本地证据与复现

证据目录：`artifacts/`（生成物，不纳入 Git）：

- `ax7010_servo_reva.net`：真实导出网表。
- `ax7010_servo_reva_erc.json`、`ax7010_servo_reva_erc.rpt`：ERC 报告。
- `schematic_review.pdf`、`schematic_svg/`：七页原理图导出。
- `pcb_drc.json`：现有 PCB 的未闭合 DRC 基线。
- `baseline/`：本轮修复前及中间阶段诊断证据。

从根目录执行五项 `tools/check_*.py` 仓库检查；原生语法检查为 `check_native_schematic.py`，旧 `check_legacy_schematic.py` 已不存在。导出网表后运行：

```sh
kicad-cli sch export netlist -o artifacts/ax7010_servo_reva.net hardware/ax7010_servo_reva.kicad_sch
python tools/check_netlist_safety.py artifacts/ax7010_servo_reva.net
kicad-cli sch erc --severity-all --exit-code-violations -o artifacts/ax7010_servo_reva_erc.rpt hardware/ax7010_servo_reva.kicad_sch
```

BOM 通过 `python tools/export_bom.py` 从原理图字段生成。本轮未提交、推送或修改 PCB。

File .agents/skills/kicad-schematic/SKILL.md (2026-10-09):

---
name: kicad-schematic
description: Safely repair KiCad 10 schematic, pin mapping, footprint assignments, hierarchical labels and BOM for the AX7010 motor-driver board, with independent ERC and datasheet review.
---

# KiCad Schematic & Footprint Gate

## Preconditions

Confirm the user-authorized repair scope, actual source SHA, KiCad 10 installation and device MPN/package drawing. Continue independent audit and repair work while requesting genuinely missing design inputs.

## Steps

1. Inspect schematic hierarchy, symbol/library and exact datasheet pinouts. Use the configured KiCad MCP / GUI, not uncontrolled file-wide regex edits. Prefer native KiCad forward annotation and versioned project libraries.
2. Limit modification to approved references (e.g. RSH1-3 and U19). Compare 4T shunt force/sense pads, ADC range, gate-driver supplies, OCP latch polarity, connectors, and off-state safety against vendor documentation.
3. Verify symbol-to-pad number and footprint geometry; re-export KiCad 10 netlist, BOM and ERC using actual `kicad-cli` commands.
4. Check cross-sheet labels remain hierarchical (no new global label unless explicit spec change), no floating wires, no object beyond A4 boundary, and avoid false NC/power flags to suppress legitimate errors.
5. Save machine-produced ERC, netlist, BOM, focused changes and datasheet page references; review the proposed PCB diff and continue within the user-authorized scope.

## Exit criteria

Apply root `AGENTS.md`'s mandatory power/GND visible-wiring rules and the
[project repair skill](../fpga-servo-kicad-repair/SKILL.md#visible-power-and-ground-wiring).
Power, ground, PWR_FLAG and child hierarchy ports must connect by visible
native wiring to real component pins; label-only isolated stubs fail acceptance.
Require `python tools/check_power_wiring.py`, baseline/final XML netlist
equivalence, native ERC and visual review of all power/ground regions.

Real footprint mapping is assigned, approved and versioned; native ERC zero error/warning on checked SHA; expected functional component/net changes intentional; BOM matches schematic. Do not claim footprint is production-qualified without datasheet/dimensional signoff.

## fpga-servo local integration

Read `docs/ai_pcb_local_setup_2026-10-09.md` and the existing project skill `.agents/skills/fpga-servo-kicad-repair/SKILL.md` before applying this workflow. Root AGENTS.md and user authorization take precedence. Use existing `tools/check_pcb_parity.py` for physical pin/net/value/DNP verification; the tutorial XML audit is supplemental. Use fresh exports rather than the tutorial historical 124-component/32-footprint baseline. Tool names must be discovered from the active MCP; do not assume a sync/router tool exists.

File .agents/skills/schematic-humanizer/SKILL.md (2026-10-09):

---
name: schematic-humanizer
description: Reorganize label-heavy or netlist-like electronic schematics into human-readable functional diagrams with visible local wiring while preserving proven connectivity. Use for schematic readability correction, overlapping wires or symbols, visually floating connectors or support logic, functional-sheet restructuring, bus presentation, layout annotations, or multi-EDA handoff across KiCad, Altium, EasyEDA, EAGLE/Fusion, gEDA/Lepton, SPICE/netlist, and PDF/image sources.
---

# Schematic Humanizer

Turn an electrically connected but label-heavy schematic into a diagram a human
can trace. Preserve the circuit unless the user separately authorizes an
electrical change. Readability is not electrical approval.

## Establish the adapter

Before editing, read [references/adapters.md](references/adapters.md) and define:

1. Native source of truth, generator, libraries, project rules, and protected
   PCB/layout artifacts.
2. Baseline connectivity exporter/parser and its limitations.
3. Normalization to `schematic-connectivity-v1`: component identity, named net,
   and every `(reference, pin)` membership.
4. Supported edit path: generator, native API, text format, or controlled GUI.
5. Renderer and ERC/lint path.
6. Repeatable post-edit export and exact comparison.

Never call an unverified conversion equivalent. If only PDF/image evidence
exists, preserve it, create a companion native drawing, and label electrical
equivalence unverified.

Read the mandatory
[visual audit checklist](references/visual-audit-checklist.md) before editing.
Record its result with
[references/visual-audit-record.md](references/visual-audit-record.md).
When layout guidance is requested or placement-sensitive buses, clocks, power,
controlled interfaces, RF, or manufacturer rules are obvious, also read
[layout handoff annotations](references/layout-handoff-annotations.md).

## Repeated power stages and KiCad presentation

For this repository, apply root `AGENTS.md`'s mandatory power/GND visible-wiring
rules and the [project repair skill](../fpga-servo-kicad-repair/SKILL.md#visible-power-and-ground-wiring).
Power, ground and PWR_FLAG graphics and child hierarchy ports must have a
visible native-wire path to real component pins. A separate power legend or
port-to-symbol stub is not an acceptable substitute. Run
`python tools/check_power_wiring.py` alongside exact native-netlist comparison
and ERC; inspect supply/return paths and every moved endpoint in the renders.

For motor-driver sheets, repeated channels, crowded hierarchy labels, title-block
collisions, or missing page-number reports, read
[practical wiring and page review](references/practical-wiring-and-pages.md).
It gives local wiring patterns and separates Git status from electrical checks.

## Workflow

1. **Capture baseline.** Read repository instructions. Export canonical
   connectivity and ERC/lint. Record hashes or a clean diff for protected
   layout files. If a generator owns the schematic, edit the generator. In a
   generated variant, trace the selected configuration and presentation or
   placement override into the generator; a defined but unused table is not
   evidence. In a recorded workflow, also render and preserve the intentionally
   netlist-style
   whole schematic before changing its presentation; this is the authoritative
   “before” frame, not a reconstructed mockup.
2. **Plan functional sheets.** Group by real flow: connector/input → protection
   or translation → processing/control → memory/output. Separate power/reset
   and repetitive decoupling when useful. Prefer left-to-right flow, power at
   top, and ground at bottom.
3. **Show local relationships.** Draw native wires for nearby connectors, USB,
   oscillators, MCU support, memory controls, translators, glue, reset/boot,
   pulls, LEDs, and power chains. Rotate connectors toward the served circuit.
   Use real buses and entries for repeated address/data groups. Reserve labels
   mainly for cross-sheet or genuinely long connections.
4. **Enforce drawing hygiene.** Never route a wire or bus under a symbol,
   reference, value, title, note, or unrelated label. Avoid wire-through-pin
   ambiguity, unintended junctions, four-way crossings, stacked labels, long
   loops, and crowded bus entries. Use orthogonal grid-aligned routes, visible
   junctions, consistent entry pitch, and sufficient whitespace.
5. **Render before annotation.** Export every sheet to PDF and readable PNG.
   Inspect whole pages, page edges, and dense crops around large ICs, modules,
   connectors, memories, buses, reset, and power. Fix every overlap, apparent
   floating function, reversed flow, clipped item, and avoidable label chain.
6. **Add justified layout guidance.** Mark each statement `[SPEC]`, `[TARGET]`,
   or `[TBD-MEASURE]`. Capture rate plus edge-rate caveat, topology/stubs,
   reference plane, skew intent, current allocation, trace/via intent,
   placement/keepout, and authoritative guidance. Keep calculations and full
   URLs in a companion document.
7. **Render again.** Reinspect every page and changed dense crop after comments.
   Reject any annotation hiding a wire, bus, pin, reference, value, heading, or
   dominant signal path.
8. **Prove preservation.** Export and normalize final connectivity with the
   same adapter. Run `python scripts/compare_connectivity.py before after`;
   KiCad XML netlists are accepted directly. Require exact identities, net
   names, and ref/pin memberships, no new ERC/lint findings, and no protected
   layout changes. After any generator configuration or override-binding
   change, prove the active variant in a deterministic manifest or sentinel
   output and repeat exact connectivity comparison; ERC alone is insufficient.

In recorded mode, append separate checkpoints for the raw schematic,
humanized all-sheet render, dense-area visual audit, and connectivity proof.
Use promotion-safe frames and keep machine reports as hashed outputs. Do not
create a fake overlap or electrical fault merely to make the transformation
look dramatic.

## Completion report

Report adapter, authoritative files, baseline/final counts, comparison result,
ERC/lint before and after, protected-file proof, every rendered page/crop
inspected, remaining limitations, and the final snapshot. Write
`.pcba-workflow/schematic-visual-audit.json`. Route circuit-design
findings to `$design-and-review-circuit` rather than mixing them into visual
approval.

For ready-to-copy user requests, read
[references/prompt-template.md](references/prompt-template.md).

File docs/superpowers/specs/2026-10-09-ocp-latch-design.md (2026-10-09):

# OCP 故障锁存设计（已确认）

## 目标与范围

将现有“故障消失即恢复”的组合 OCP 改成硬件锁存关断。保持 J1 PWM、GATE_EN、FAULT_CLEAR、OCP_N 的既有接口分配；不依赖 FPGA 固件才能关断。用户已于 2026-10-09 确认本规格，实施记录见对应计划与后续审查。

本子任务只实现安全使能锁存及上电复位。母线浪涌/再生功率级与最终 PCB 布线分阶段处理，不能用本子任务完成代替整板工业级验收。

## 方案比较

1. **推荐：异步清零 D 触发器作为 ARM 锁存**。电源/故障条件强制清零；FAULT_CLEAR 上升沿仅在 GATE_EN=0 时重新武装。可以明确验证清除保持、重复故障和上电状态。
2. 交叉耦合 NOR/SR 锁存：器件常见，但同时置位/复位及上电状态须额外约束，不选作本轮默认方案。
3. FPGA 维护软件故障状态：不能替代独立硬件锁存，不采用。

## 电气行为与连接意图

- 新增 SN74LVC1G74（3.3V）作为 ARM 锁存；具体订货后缀及封装按制造商机械图选定。
- D 接反相后的 GATE_EN；CLK 接有明确下拉及边沿整形的 FAULT_CLEAR。
- /PRE 固定接 VIO_3V3，避免与 /CLR 同时有效。
- /CLR 接 HEALTHY_N：只有原始 OCP 正常、12V/5V PWR_GOOD 正常且电源复位监控有效时，/CLR 才为高。任何故障异步清零 ARM。
- Q=ARMED。U11 的第三输入从原始 OCP_N 改接 ARMED，RUN_OK=GATE_EN & PWR_GOOD & ARMED。
- 原始 OCP_N 保留给 FPGA 作实时诊断；锁存状态引出测试点。FAULT_CLEAR 通过现有 J1 pin 10 实际接入硬件。
- 使用电源监控器确定 VIO_3V3 上电/欠压复位，且验证 VA_5V 失电也产生硬件禁止。不得依赖普通 RC 或触发器的未知上电值建立 ARM 初值。
- 每颗新增 IC 有独立 100nF 本地去耦；默认偏置器件必须装配，不作 DNP。

这里描述的是连接意图。新增监控器的阈值、延迟、开漏断电行为及触发器恢复/移除时间须在后续实现计划中逐项由数据手册和容差计算确定，再写入原理图。

## 状态验收表

| 条件 / 操作 | ARMED | RUN_OK |
|---|---:|---:|
| 上电复位有效 | 0 | 0 |
| 健康但未执行有效 FAULT_CLEAR 边沿 | 0 | 0 |
| 健康、GATE_EN=0，FAULT_CLEAR 上升沿 | 1 | 0 |
| 已武装且健康，GATE_EN=1 | 1 | 1 |
| 任一 OCP 或电源故障 | 0 | 0 |
| 故障消失但无新清除边沿 | 0 | 0 |
| 故障中执行 FAULT_CLEAR | 0 | 0 |
| GATE_EN=1 时执行 FAULT_CLEAR | 0 | 0 |
| FAULT_CLEAR 持续高，故障发生又消失 | 0 | 0 |

GATE_EN 高时的清除脉冲应解除武装而非允许运行；清除操作顺序固定为 GATE_EN 拉低、确认健康、发出清除边沿、再允许 GATE_EN 拉高。

## 验证要求

- 自动网表检查验证 D/CLK、/CLR、/PRE、ARMED 与 U11 的真实引脚连接及默认偏置。
- 行为/时序验证覆盖表内全部场景、清除与故障竞争、短故障脉冲、FAULT_CLEAR 卡高、VIO/VA_5V/VDRV_12V 不同上下电顺序。
- 根据数据手册最坏延迟形成 OCP 到 FD6288 输入的关断时间预算，计入输入 RC、比较器、清零及逻辑延迟；台架用实际 gate-to-source 波形确认。
- 仓库检查、BOM 一致性和 ERC 必须通过；任何违规必须修复或记录真实原因，不降低规则清零。
- 该单通道硬件禁止不是安全认证的 STO，不作 SIL/PL 声明。

## 数据来源

- [TI SN74LVC1G74 数据手册](https://www.ti.com/lit/ds/symlink/sn74lvc1g74.pdf)
- [TI TLV9024 数据手册](https://www.ti.com/lit/ds/symlink/tlv9024.pdf)

## 审阅决定

用户已确认采用“故障锁存；GATE_EN=0 且健康时，FAULT_CLEAR 上升沿重新武装”的策略。按逐器件实施计划执行原理图和回归修改。

## 实施细化

开漏 POR/OCP/PG 经 U26 三通道施密特缓冲，PWR_READY 是 PWR_GOOD 的整形信号；RUN_OK 实际为 GATE_EN & PWR_READY & ARMED。此细化保持原故障优先和低使能边沿重武装行为。最终 158 器件 / 183 网络；时序条件和台架门槛见 `docs/ocp_latch_review_2026-10-09.md`。

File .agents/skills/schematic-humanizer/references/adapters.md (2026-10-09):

# EDA adapters / EDA アダプター

Use native exporters whenever possible. An adapter is acceptable only when it can repeat the same normalization before and after editing.

可能な限り EDA の標準エクスポートを使い、変更前後で同じ正規化手順を再現できる場合だけ同一性を判定します。

## Generated schematic binding guard

When a generator supports variants or separate presentation/placement tables,
record the source module, selected variant, active override table, generator
version, and output hash. Prove that the selected override is consumed with a
deterministic manifest, trace, or harmless sentinel fixture. Reject silent
fallback to default placement even when generation and ERC succeed. After a
binding change, regenerate from a clean state and repeat exact connectivity and
all-sheet visual comparison.

| Source | Safe source/edit path | Connectivity and render evidence | Limitations / 注意点 |
|---|---|---|---|
| **KiCad — first class / 最優先対応** | Detect `.kicad_pro`, `.kicad_sch`, symbol tables, and any generator. Edit generator or native schematic. | Export KiCad XML netlists before/after with `kicad-cli sch export netlist --format kicadxml`; compare directly with `compare_connectivity.py`. Run native ERC. Export PDF and render all pages. | KiCad CLI defaults to its S-expression netlist, so request XML explicitly. Preserve references, net names, pin numbers, and PCB bytes. Net codes, coordinates, timestamps, and sheet paths are presentation/export metadata. |
| **Altium Designer** | Treat `.PrjPcb`, `.SchDoc`, libraries, parameters, and scripts as authoritative. Use Altium UI/automation; do not hex-edit binary documents. | Export a netlist/report containing designator, pin, and net; write a deterministic adapter to canonical JSON. Publish schematic PDF and ERC/compiler report. | Export dialects vary by version/template. Prove field mapping on a small sample; state if hidden harness, variant, or multi-part data is omitted. |
| **EasyEDA Standard/Pro** | Identify Standard vs Pro and whether JSON/source export or cloud project is authoritative. Edit through the matching editor or documented project format. | Export netlist/design data and PDF from the same edition; normalize references, pin numbers, and net names to canonical JSON. Run its design checks. | Standard and Pro formats differ. Do not assume a third-party parser preserves internal IDs, net ties, or multi-unit semantics. |
| **EAGLE / Autodesk Fusion Electronics** | For legacy EAGLE XML `.sch`, use a tested XML adapter or native editor. For Fusion-managed projects, use Fusion export/API rather than editing cache files. | Normalize `<parts>`, `<nets>`, `<segment>`, and `<pinref>` from EAGLE XML, or use a Fusion netlist export. Print/export every schematic sheet. | Supply pins and implicit nets may need library resolution. Fusion exports can differ from legacy EAGLE XML; document the version. |
| **gEDA / Lepton EDA** | Treat text `.sch`, symbol libraries, and project scripts as source. Use native tools or deliberate text edits that preserve attributes. | Use `gnetlist` or `lepton-netlist` output plus a documented normalizer; render with the matching native tool and run available checks. | Slotting, inherited attributes, and library search paths affect pin identity. Capture tool and library versions. |
| **SPICE or other netlist source** | Treat the text netlist and included models/subcircuits as source. Preserve node order and `.include` resolution. A newly drawn schematic may be a companion artifact rather than the source. | Parse instances, node positions, and subcircuit pin definitions into canonical refs/pins/nets; compare source text semantics and run the simulator/parser. | SPICE node order is device/model dependent and may not contain PCB footprints or display names. State the pin-mapping assumptions. |
| **PDF/image only / PDF・画像のみ** | Do not overwrite the only evidence. Trace into a new native schematic or create a visual companion diagram. | Render/inspect visually and keep a transcription log. Compare OCR/manual observations only as review aids. | Electrical equivalence is **unverifiable** without native source or a trusted netlist. Mark uncertain pins/nets and request better source material. |

## Canonical JSON

Use UTF-8 JSON with this shape:

```json
{
  "schema": "schematic-connectivity-v1",
  "components": [
    {"ref": "R1", "value": "1k", "footprint": "R_0603", "device": "Device:R"}
  ],
  "nets": [
    {"name": "SIGNAL", "pins": [{"ref": "R1", "pin": "1"}, {"ref": "U1", "pin": "4"}]}
  ]
}
```

Sort order is irrelevant. References, pin identifiers, net names, and component identity strings are exact and case-sensitive. Adapters may leave `value`, `footprint`, or `device` empty only when the source does not provide them; use the same policy before and after.

並び順は不問です。リファレンス、ピン、ネット名、部品情報は大文字小文字を含めて厳密比較します。取得できない項目は変更前後で同じ空欄ポリシーを使います。

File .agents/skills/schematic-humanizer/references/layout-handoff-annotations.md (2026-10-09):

# Layout handoff annotations / レイアウト引き継ぎ注記

Add layout annotations when the user explicitly requests them or when the source
clearly exposes placement-sensitive interfaces. Do not guess hidden electrical
requirements. Ask the user only when the missing choice would materially change
the design; otherwise mark it for measurement or engineering review.

ユーザーの明示要求、または回路から配置・配線制約を明確に判断できる場合に
注記を追加する。不明な電気条件を推測しない。設計を大きく変える選択だけを
質問し、それ以外は要実測・要レビューとして明記する。

## Evidence classes / 根拠区分

- `[SPEC]`: manufacturer datasheet, interface standard, approved project
  requirement, or verified measured value. Include the source in the companion
  document.
- `[TARGET]`: conservative project routing allocation chosen for this revision,
  such as loose group skew, firmware-rate ceiling, current capacity, or layer
  preference. Explain that it is not certified timing or measured current.
- `[TBD-MEASURE]`: source capability, thermal rise, real current, unknown clock,
  enclosure RF performance, or another item that cannot be proven from the
  schematic.

- `[SPEC]`: データシート、規格、承認済み要件、確認済み実測値。
- `[TARGET]`: この版の保守的な設計目標。タイミング保証や実測値ではない。
- `[TBD-MEASURE]`: 電流、温度、電源能力、未知クロック、筐体 RF など要確認項目。

## What to capture / 記載項目

For each meaningful interface or rail, capture only applicable items:

1. Clock, data rate, or access cadence, plus the warning that edge rate can set
   signal-integrity risk even when the clock is slow.
2. Required topology and stub rule: source → buffer/termination → receiver,
   point-to-point, daisy chain, star, or explicitly forbidden branches.
3. Reference plane, layer preference, controlled impedance, spacing, and return
   transition guidance.
4. Group skew or pair mismatch target. Avoid meanders when the timing budget
   does not require them.
5. Provisional current allocation, shared-trunk capacity, trace/pour and via
   intent, voltage-drop/thermal signoff, and measurement state.
6. Component placement: decoupling escape path, regulator loop, crystal, antenna
   keepout, connector ESD, exposed-interface protection, and mechanical keepouts.
7. Authoritative manufacturer or standards URL in a companion layout guide.

クロック/データレート、エッジレート、トポロジ、スタブ、基準面、層、
インピーダンス、長さ差、暫定電流、配線幅・ビア、配置、メーカー資料を、
該当する範囲だけ記載する。

## Presentation / 表示方法

- Put short, local callouts near the relevant functional region, but outside
  wires, buses, symbols, labels, and the dominant visual flow.
- Keep full calculations, current-budget tables, URLs, assumptions, and signoff
  checklists in a companion Markdown/PDF document. Link it with a short on-sheet
  note.
- Do not label an entire design with one clock when domains differ. Separate CPU,
  memory, loader, RF, USB, and other interfaces.
- Do not add a generic impedance width/gap before the final fabricator stackup is
  known. State the impedance and reference plane, then require stackup-derived
  geometry.
- Treat a vendor module with an integrated antenna as a placement/keepout problem;
  do not invent an RF feed trace that is not in the circuit.

注記は関連機能の近くに短く置き、配線や信号の流れを隠さない。計算、表、
完全な URL、前提、承認項目は別文書へ移す。異なるクロック領域を一つの速度
で表現せず、最終スタックアップ前に汎用線幅を固定しない。

## Required final gate / 必須最終確認

Annotations can introduce new overlaps. After adding them, follow the complete
[visual audit checklist](visual-audit-checklist.md), including every full page
and dense crops around the annotated regions. Then repeat connectivity comparison
and ERC/lint. A clean netlist does not excuse a visually obscured schematic.

注記追加後は全ページと高密度部分を再レンダリングし、目視監査、接続比較、
ERC を繰り返す。ネットリストが正しくても、注記が回路を隠す場合は不合格。

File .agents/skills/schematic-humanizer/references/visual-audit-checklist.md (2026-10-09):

# Visual audit checklist / 目視監査チェックリスト

This checklist is mandatory after every meaningful schematic rearrangement and
again after adding comments or layout guidance. Passing ERC does not pass the
visual audit.

このチェックリストは、回路図の再配置後と注記追加後に必ず実施する。ERC
が合格しても、目視監査の代わりにはならない。

## Routing and buses / 配線とバス

- Do not maximize wire count. Prefer direct local wiring where it clarifies a
  relationship, and matched labels where a long wire would create a loop or
  spaghetti.
- Keep every bus spine outside symbol bodies, values, references, notes, and
  unrelated labels. Large MCUs and modules need extra clearance.
- Never place two different bus spines collinearly on top of one another.
- Avoid wire-through-pin paths that can look connected or create accidental
  connectivity. Make branches and junctions explicit.
- Use the native grid and snap bus entries to it. Keep entry pitch and direction
  consistent.
- In tools where wires are two-point segments, emit a separate segment for each
  bend. Split bus backbones at T-tap endpoints when the format requires explicit
  junction geometry.
- Move pulls, termination parts, decouplers, and interface passives near the
  circuit they support when this makes the function readable.

- 配線本数を増やすことを目標にしない。近接関係は実配線で示し、長い迂回
  配線がスパゲッティ化する場合は対応ラベルを使う。
- バス幹線を部品、値、リファレンス、注記の下へ通さない。異なるバスを
  同一直線上で重ねず、T 分岐と接続点を明確にする。
- グリッドとスナップを使い、バスエントリの間隔と方向を統一する。
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

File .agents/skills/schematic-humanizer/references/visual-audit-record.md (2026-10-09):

# Schematic visual-audit record

Write UTF-8 JSON to `.pcba-workflow/schematic-visual-audit.json`:

```json
{
  "schema": "schematic-visual-audit-v1",
  "status": "PASS|BLOCKED|USER_REVIEW",
  "source_type": "",
  "adapter": "",
  "authoritative_sources": [],
  "baseline_connectivity": "",
  "final_connectivity": "",
  "connectivity_result": "PASS|BLOCKED|UNVERIFIABLE",
  "erc_or_lint": {"before": "", "after": ""},
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

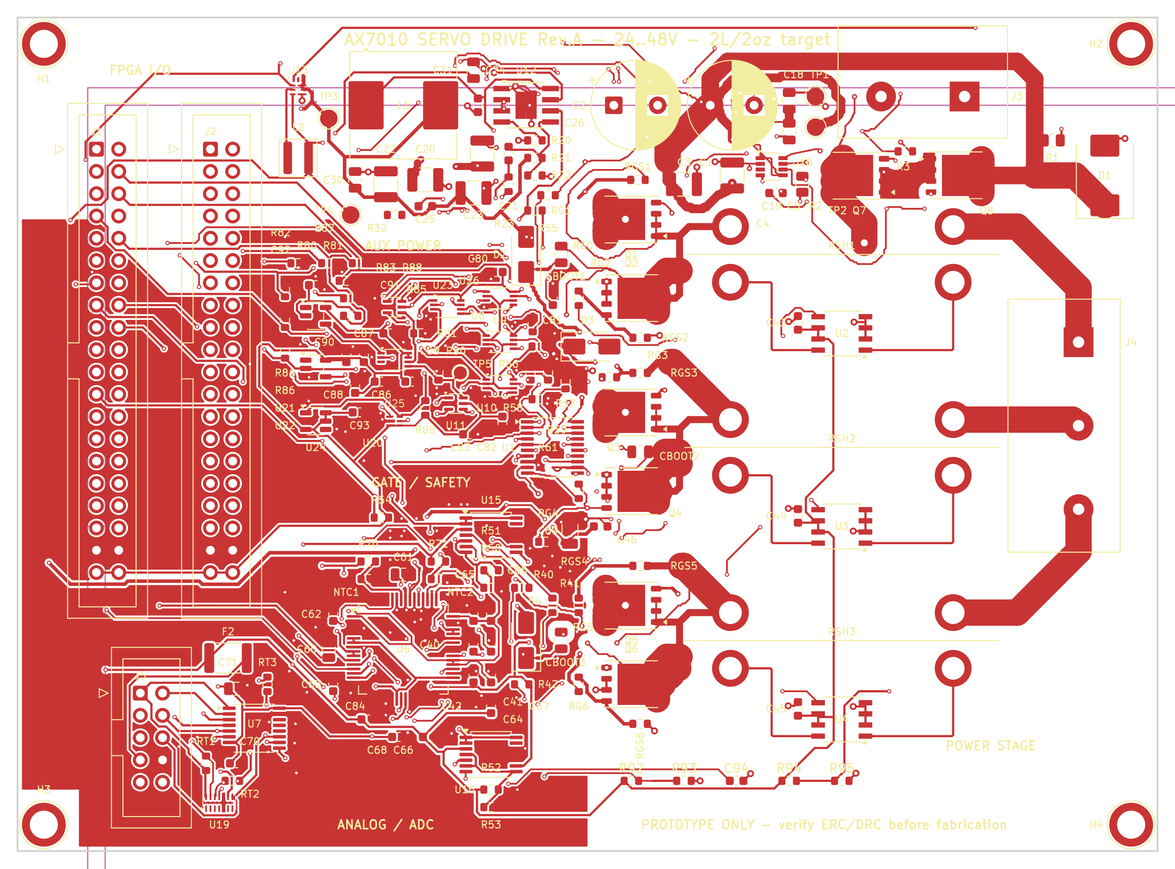
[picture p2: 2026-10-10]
docs/reviews/pcb_corners_copper_2026-10-10/after-front.png

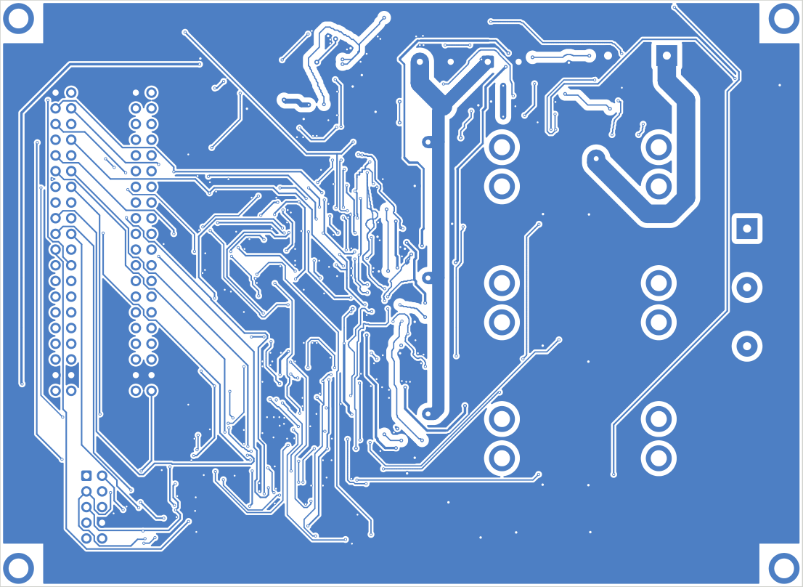
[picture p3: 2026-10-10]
docs/reviews/routing_completion_2026-10-10/final-back.png

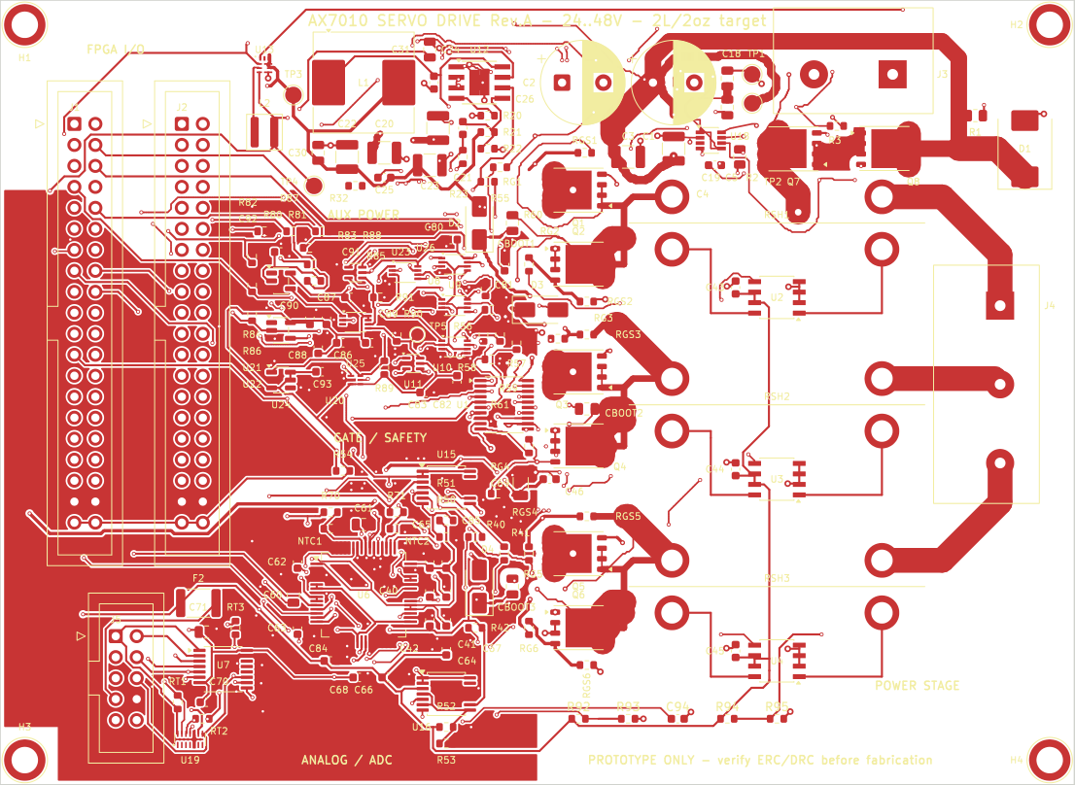
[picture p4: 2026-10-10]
docs/reviews/routing_completion_2026-10-10/final-front.png

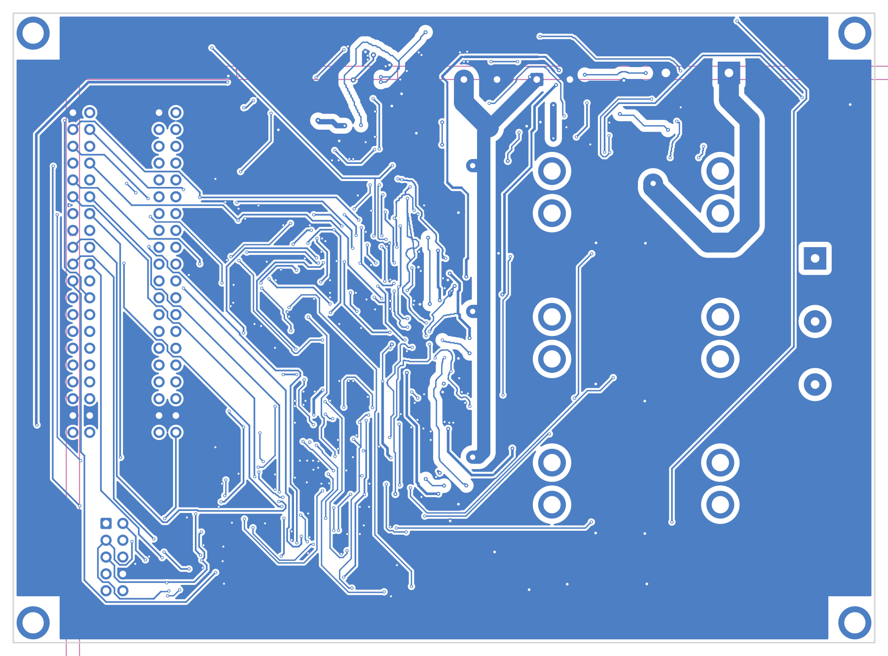
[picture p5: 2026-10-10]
docs/reviews/pcb_corners_copper_2026-10-10/after-back.png

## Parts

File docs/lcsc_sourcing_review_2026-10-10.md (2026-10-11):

# LCSC sourcing review — 2026-10-10

**Current delivery scope (user revision, 2026-10-10): BOM and schematic only. PCB/layout repair is deferred. The working PCB retains earlier development edits and is not synchronized to the final bus-OCP schematic; the isolated unfinished routing candidate is not adopted. Do not use this board for fabrication or reuse historical zero-DRC/parity claims for the current schematic.**

The current procurement export covers **148 fitted purchased references in 68 groups** from the merged 159-component BOM. All 68 selected groups have dated Chinese-storefront stock sufficient for five boards plus 20% spares, rounded to the recorded order multiple. This is **limited-energy prototype sourcing eligibility**, not fabrication approval, a stock reservation, a checkout quotation, or full-power component qualification. PCB DRC, electrical release gates and bench validation are reported separately; this review does not assert final DRC clearance.

`python tools/export_procurement.py` regenerates [procurement_candidates.csv](../hardware/procurement_candidates.csv) from the current BOM and [selected overrides](sourcing/selected_overrides_2026-10-10.json). Overrides take precedence over historical grouped candidates. A BOM MPN, C-code or required-footprint mismatch becomes `SELECTED_PENDING_BOM_OR_FOOTPRINT`; missing evidence becomes `UNRESOLVED_SOURCE_EVIDENCE`. Unqualified candidates and insufficient inventory remain separate dispositions. Every fitted purchased reference appears once. Unknown future references cannot inherit qualification merely by sharing a value or MPN.

Historical `passive_2026-10-10.json`, `critical_2026-10-10.json` and `shunt_2026-10-10.json` remain unchanged. New `*_selected_evidence_*` and `*_selected_stock_*` files preserve the later source records, OEM links, timestamps and qualification conditions. Displayed prices are reference starting prices, not quantity-tier quotes. Refresh stock and checkout multiples before ordering.

## Final selected changes

| References | Selected part / Chinese LCSC code | Scope and remaining conditions |
|---|---|---|
| U1 | TI DRV8300DPWR / C3036056 | Noninverting D version, internal bootstrap diodes; critical single-source exception. Gate discharge, UVLO, bootstrap refresh, SH slew and power-stage validation remain open. |
| CBOOT1–3 | Fenghua 0805B474K500NT / C49955 | 470 nF, 50 V, X7R, 0805. The illustrative 143 nC / 1 V bootstrap budget requires ≥143 nF effective capacitance; actual maximum charge/on-time still needs qualification. Keep maximum capacitance ≤1 µF. Generic OEM data do not prove the bias minimum. Walsin alternate has the same application gate. |
| RG1–6 | Fenghua RS-03K33R0FT / C125766 | 33 Ω, 1%, 0603; UNI-ROYAL alternate. Gate pulse and switching tuning remain open. |
| F1 | Littelfuse 0456025.ER / C315877 | Onboard SMD fuse. Exact 25 A row: 500 A interruption at 72 VDC, 1000 A at 32 VDC. Do not transfer the catalog 125 V label into a DC rating. Source fault level, thermal derating, inrush and coordination remain open; no qualified direct alternate. |
| U2–5 | TI INA240A1DR / C2060769 | Gain 20 V/V. Phase channels retain 5 mΩ sensing; U5 measures positive bus current with grounded references and 2 mΩ shunt. Common-mode transients/recovery remain open. |
| U15 | TI LM393LVDDFR / C5213974 | One active positive bus OCP comparator. Input and output tolerate independent 0–5.5 V with supply off; POR output is high impedance. Unused comparator inputs are separated and output NC. No intrinsic hysteresis; complete latch/timing/noise verification remains necessary. |
| RSH4 | Milliohm HoYLR2512-3W-2mR-1% / C5375458 | 2 mΩ, 3 W, 1%; 1.25 W at 25 A. RALEC alternate requires different recommended land review; thermal/pulse qualification remains open. |
| R50 / R53 | RESI PTFR0603B8K20P9 / C351624; Fenghua TD03G2001BT / C666953 | 8.2 kΩ / 2.0 kΩ, 0.1%, 25 ppm/°C, 0603. From 5.1 V, threshold is nominally 1 V = +25 A with gain20 and 2 mΩ. Yageo/Panasonic alternatives are separately recorded. |
| RSH1–3 | Milliohm HoYLR2512-3W-5mR-1% / C5375461 | Native two-terminal lands with Kelvin pickups. 0.5 W at 10 A; 2 W at 20 A. RALEC alternate and all thermal/assembly qualification remain conditional. |
| J1 / J5 | JILN 321040SG0ABK00A01 / C601944; 321010SG0ABK00A01 / C429962 | OEM key slot on odd-pin side, 2.54 mm grid. Shared recommended finished hole 1.02 ±0.03 mm fits both candidate vendor limits. BOOMELE alternatives remain conditional on OEM provenance and ≤1 A/pin demand; JILN is rated 3 A. |
| F2 | JDT ASMD1812-050 / C135358 | 15 V PTC, 0.5 A hold near room temperature. Local ambient ≤85°C and derated hold current required. Bourns MF-MSMF050-2 / C17313 has a different recommended land and remains conditional. |
| NTC1–2 | Shiheng CMFA 103F3950 / C2889049 | OEM NTC land; KUU alternate requires the same temperature calibration and assembly checks. |
| J4 | KEFA KF950-9.5-3P / C475107 | Vendor footprint selected; connection resistance, wiring and full-load heating remain release checks. |
| L1 | SOREDE SDRH.1209.LF680MT00 / C2942326 | 68 µH, native OEM land. Initial total 12 V load ≤0.5 A is a conservative test cap. No OEM Irms rating; guaranteed 1 A, hot inductance and thermal performance unresolved. No qualified alternate. |
| L2 | Sunlord SWPA4020S2R2MT / C83423 | Exact M20 OEM data and native land reviewed. cjiang FHD4020S-2R2MT / C602029 shares the OEM land; hot/thermal/assembly validation remains open. |
| C3 / C4 / C94 | Faratronic C212E105J6BC000 / C604836; TDK C4532C0G2A104JT000N / C342611; Murata GRT31C5C1H104FA02L / C3839854 | Corrected P15 film, 1812 C0G and 1206 C0G footprints. C3 bus pulse/ripple and C94 recovery timing remain application gates. A 5% C94 alternative is not an equivalent for the selected 1% requirement. |
| R92 | Fenghua TD03G3241BT / C666977 | Selected 3.24 kΩ, 0.1%, ≤25 ppm/°C specification and static corner budget; Yageo RT0603BRB073K24L / C860367 alternate. Qualification-test drift limits are not guaranteed lifetime drift bounds. |

## Exclusions and interpretation

U16, R51, R52, D2–D4 and J2 are removed by the final architecture. D1, R32 and RT1–3 are DNP options. J6 is an external system interface; F1_HOLDER is obsolete. TP1–5 are bare PCB pads and need no MPN. None contributes to order quantity.

Domestic preference means mainland manufacturers such as Fenghua, RESI, Milliohm, JILN, JDT, Shiheng, KEFA, SOREDE and Sunlord. Taiwan manufacturers such as Yageo, UNI-ROYAL, RALEC and Walsin are identified separately; they are not described as mainland brands. Critical imported exceptions and unavailable or conditional alternates remain explicit in the evidence.

The CSV's `SOURCED_PROTOTYPE_ELIGIBLE` disposition confirms source evidence, current BOM identity and available snapshot quantity. It does not close the conditions in `Qualification`, `Alternate qualification` or `Notes`, and it does not authorize substituting an alternate automatically. No parts have been purchased or reserved by this export.

C19 and C25 now have stocked cross-manufacturer alternates: Walsin 0805B104K101CT / C77456 (100 nF, 10%, 100 V, X7R, 0805; China stock 26,000 at 15:34:54 UTC) and Yageo CC0603JRX7R9BB332 / C519530 (3.3 nF, 5%, 50 V, X7R, 0603; stock 34,900 at 15:35:03 UTC). OEM package and parameter evidence is recorded in [the alternate snapshot](sourcing/c19_c25_alternate_evidence_2026-10-10.json); both retain existing lands. Walsin and Yageo are Taiwan manufacturers. C19 bus transients/DC bias and C25 control-loop tuning remain application checks. The earlier Walsin 5% suggestion was rejected for zero stock. J4 now links to the [KEFA manufacturer product](https://www.cnkefa.com/products/7736.html), correcting the historical Phoenix link.

## Final schematic verification

Fresh native export: 159 system objects /135 nets; PCB-target native netlist:158 components /135 nets. ERC:0 errors /0 warnings /0 exclusions; four pre-existing ignored categories were not changed. Five schematic/grid/layout/connectivity/power-wiring checks, physical-pin safety, 531 digital latch scenarios, six ADC tests and 27 Gate A/B tests pass. All eight PDF pages and dense supply/ground regions were visually reviewed.

`check_design.py` remains FAILED because the deferred working PCB lacks the final U5/RSH4/U15 footprint and package-rule changes. This is recorded without reducing severities or exclusions. Gate A/B remain BLOCKED for electrical/thermal/dynamic qualification. The isolated unfinished PCB candidate was not adopted.

Evidence: [verification JSON](reviews/selection_2026-10-10/verification.json), [native ERC](reviews/selection_2026-10-10/erc.json), [reviewed schematic PDF](reviews/selection_2026-10-10/schematic.pdf), [physical-pin delta](reviews/selection_2026-10-10/physical-pin-delta.json).

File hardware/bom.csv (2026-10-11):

Ref | Qty | Value / Part | Manufacturer | MPN | Package | LCSC | Alternative MPN | Alternative LCSC | Alternative status | Sourcing status | Function | Status / note
C1 | 1 | 100uF | NCC(日本贵弥功) | EKZN101ELL101MJ20S | Capacitor_THT:CP_Radial_D10.0mm_P5.00mm | C337258 | 100ZLH100MEFC10X20 | C330940 | READY_FOR_PROTOTYPE | Prototype candidate; OEM reviewed; stock checked 2026-10-10; not production-qualified | 100uF_100V | Fitted
C2 | 1 | 100uF | NCC(日本贵弥功) | EKZN101ELL101MJ20S | Capacitor_THT:CP_Radial_D10.0mm_P5.00mm | C337258 | 100ZLH100MEFC10X20 | C330940 | READY_FOR_PROTOTYPE | Prototype candidate; OEM reviewed; stock checked 2026-10-10; not production-qualified | 100uF_100V | Fitted
C3 | 1 | 1uF | Faratronic | C212E105J6BC000 | Capacitor_THT:C_Rect_L18.0mm_W8.0mm_P15.00mm_FKS3_FKP3 | C604836 | UNQUALIFIED | UNVERIFIED | OPEN | OPEN | 1uF_100V_FILM | Fitted
C4 | 1 | 100nF | TDK | C4532C0G2A104JT000N | Capacitor_SMD:C_1812_4532Metric | C342611 | FM43N104J101EGG | C42391415 | READY_FOR_PROTOTYPE_AFTER_FOOTPRINT_UPDATE | OPEN | 100nF_100V_C0G | Fitted
C5 | 1 | 10nF | FH(风华) | 0603B103K101NT | Capacitor_SMD:C_0603_1608Metric | C43253 | CL10B103KB8NNNC | C1589 | READY_FOR_PROTOTYPE | Prototype candidate; OEM reviewed; stock checked 2026-10-10; not production-qualified | 10nF_VBUS_SENSE | Fitted
C18 | 1 | 220nF | FH(风华) | 0805B224K500NT | Capacitor_SMD:C_0805_2012Metric | C163697 | CL21B224KBFNNNE | C5378 | READY_FOR_PROTOTYPE | Prototype candidate; OEM reviewed; stock checked 2026-10-10; not production-qualified | 220nF_25V_VCAP | Fitted
C19 | 1 | 100nF | FH(风华) | 0805B104K101NT | Capacitor_SMD:C_0805_2012Metric | C89258 | 0805B104K101CT | C77456 | READY_FOR_PROTOTYPE; OEM same nominal/tolerance/voltage/X7R/package reviewed; application and first-article checks OPEN | Stocked prototype primary and cross-manufacturer alternate; China stock checked2026-10-10; OEM package reviewed; not production-qualified | 100nF_VS_BYPASS | Fitted
C20 | 1 | 2.2uF | FH(风华) | 1210B225K101NT | Capacitor_SMD:C_1210_3225Metric | C42400139 | GCJ32DR72A225KA01L | C388903 | READY_FOR_PROTOTYPE | Prototype candidate; OEM reviewed; stock checked 2026-10-10; not production-qualified | 2.2uF_100V_X7R | Fitted
C21 | 1 | 2.2uF | FH(风华) | 1210B225K101NT | Capacitor_SMD:C_1210_3225Metric | C42400139 | GCJ32DR72A225KA01L | C388903 | READY_FOR_PROTOTYPE | Prototype candidate; OEM reviewed; stock checked 2026-10-10; not production-qualified | 2.2uF_100V_X7R | Fitted
C22 | 1 | 22uF | FH(风华) | 1210B226K250NT | Capacitor_SMD:C_1210_3225Metric | C5204920 | CS3225X7R226K250NRL | C2918511 | BLOCKED_EXACT_OEM_SHEET_MISMATCH | Prototype candidate; OEM reviewed; stock checked 2026-10-10; not production-qualified | 22uF_25V_X7R | Fitted
C23 | 1 | 22uF | FH(风华) | 1210B226K250NT | Capacitor_SMD:C_1210_3225Metric | C5204920 | CS3225X7R226K250NRL | C2918511 | BLOCKED_EXACT_OEM_SHEET_MISMATCH | Prototype candidate; OEM reviewed; stock checked 2026-10-10; not production-qualified | 22uF_25V_X7R | Fitted
C24 | 1 | 2.2nF | FH(风华) | 0603B222J500NT | Capacitor_SMD:C_0603_1608Metric | C60328 | CL10B222KB8NNNC | C16033 | READY_FOR_PROTOTYPE | Prototype candidate; OEM reviewed; stock checked 2026-10-10; not production-qualified | 2.2nF_BST_50V | Fitted
C25 | 1 | 3.3nF | FH(风华) | 0603B332J500NT | Capacitor_SMD:C_0603_1608Metric | C20616243 | CC0603JRX7R9BB332 | C519530 | READY_FOR_PROTOTYPE; OEM same nominal/tolerance/voltage/X7R/package reviewed; application and first-article checks OPEN | Stocked prototype primary and cross-manufacturer alternate; China stock checked2026-10-10; OEM package reviewed; not production-qualified | 3.3nF_CA_X7R | Fitted
C26 | 1 | 56pF | FH(风华) | 0603CG560J500NT | Capacitor_SMD:C_0603_1608Metric | C1676 | CL10C560JB81PNC | C472797 | BLOCKED_ZERO_STOCK | Prototype candidate; OEM reviewed; stock checked 2026-10-10; not production-qualified | 56pF_CB_C0G | Fitted
C30 | 1 | 10uF | Chinocera(华瓷) | HGC0805R7106K250NSLJ | Capacitor_SMD:C_0805_2012Metric | C33546010 | FCC0805B106K250FT | C54619707 | READY_FOR_PROTOTYPE | Prototype candidate; OEM reviewed; stock checked 2026-10-10; not production-qualified | 10uF_25V_X7R | Fitted
C31 | 1 | 22uF | HRE(芯声) | CGA0805X7R226M100MT | Capacitor_SMD:C_0805_2012Metric | C23692981 | GRM21BZ71A226ME15L | C907991 | READY_FOR_PROTOTYPE | Prototype candidate; OEM reviewed; stock checked 2026-10-10; not production-qualified | 22uF_10V_X7R | Fitted
C40 | 1 | 1nF | FH(风华) | 0603CG102J101NT | Capacitor_SMD:C_0603_1608Metric | C88489 | CL10C102JB8NNNC | C163508 | READY_FOR_PROTOTYPE | Prototype candidate; OEM reviewed; stock checked 2026-10-10; not production-qualified | 1nF_C0G_ADC | Fitted
C41 | 1 | 1nF | FH(风华) | 0603CG102J101NT | Capacitor_SMD:C_0603_1608Metric | C88489 | CL10C102JB8NNNC | C163508 | READY_FOR_PROTOTYPE | Prototype candidate; OEM reviewed; stock checked 2026-10-10; not production-qualified | 1nF_C0G_ADC | Fitted
C42 | 1 | 1nF | FH(风华) | 0603CG102J101NT | Capacitor_SMD:C_0603_1608Metric | C88489 | CL10C102JB8NNNC | C163508 | READY_FOR_PROTOTYPE | Prototype candidate; OEM reviewed; stock checked 2026-10-10; not production-qualified | 1nF_C0G_ADC | Fitted
C43 | 1 | 100nF | FH(风华) | 0603B104K500NT | Capacitor_SMD:C_0603_1608Metric | C30926 | CL10B104KB8NNNC | C1591 | READY_FOR_PROTOTYPE | Prototype candidate; OEM reviewed; stock checked 2026-10-10; not production-qualified | 100nF_INA_DECOUPLE | Fitted
C44 | 1 | 100nF | FH(风华) | 0603B104K500NT | Capacitor_SMD:C_0603_1608Metric | C30926 | CL10B104KB8NNNC | C1591 | READY_FOR_PROTOTYPE | Prototype candidate; OEM reviewed; stock checked 2026-10-10; not production-qualified | 100nF_INA_DECOUPLE | Fitted
C45 | 1 | 100nF | FH(风华) | 0603B104K500NT | Capacitor_SMD:C_0603_1608Metric | C30926 | CL10B104KB8NNNC | C1591 | READY_FOR_PROTOTYPE | Prototype candidate; OEM reviewed; stock checked 2026-10-10; not production-qualified | 100nF_INA_DECOUPLE | Fitted
C46 | 1 | 100nF | FH(风华) | 0603B104K500NT | Capacitor_SMD:C_0603_1608Metric | C30926 | CL10B104KB8NNNC | C1591 | READY_FOR_PROTOTYPE | Prototype candidate; OEM reviewed; stock checked 2026-10-10; not production-qualified | 100nF_DRV | Fitted
C60 | 1 | 10uF | Chinocera(华瓷) | HGC0805R7106K250NSLJ | Capacitor_SMD:C_0805_2012Metric | C33546010 | FCC0805B106K250FT | C54619707 | READY_FOR_PROTOTYPE | Prototype candidate; OEM reviewed; stock checked 2026-10-10; not production-qualified | 10uF_REFIO_X7R | Fitted
C61 | 1 | 10uF | Chinocera(华瓷) | HGC0805R7106K250NSLJ | Capacitor_SMD:C_0805_2012Metric | C33546010 | FCC0805B106K250FT | C54619707 | READY_FOR_PROTOTYPE | Prototype candidate; OEM reviewed; stock checked 2026-10-10; not production-qualified | 10uF_REFCAP_X7R | Fitted
C62 | 1 | 1uF | FH(风华) | 0603B105K250NT | Capacitor_SMD:C_0603_1608Metric | C59302 | CL10B105KA8NNNC | C29936 | BLOCKED_ZERO_STOCK | Prototype candidate; OEM reviewed; stock checked 2026-10-10; not production-qualified | 1uF_REGCAP1 | Fitted
C63 | 1 | 1uF | FH(风华) | 0603B105K250NT | Capacitor_SMD:C_0603_1608Metric | C59302 | CL10B105KA8NNNC | C29936 | BLOCKED_ZERO_STOCK | Prototype candidate; OEM reviewed; stock checked 2026-10-10; not production-qualified | 1uF_REGCAP2 | Fitted
C64 | 1 | 1uF | FH(风华) | 0603B105K250NT | Capacitor_SMD:C_0603_1608Metric | C59302 | CL10B105KA8NNNC | C29936 | BLOCKED_ZERO_STOCK | Prototype candidate; OEM reviewed; stock checked 2026-10-10; not production-qualified | 1uF_AVDD1 | Fitted
C65 | 1 | 1uF | FH(风华) | 0603B105K250NT | Capacitor_SMD:C_0603_1608Metric | C59302 | CL10B105KA8NNNC | C29936 | BLOCKED_ZERO_STOCK | Prototype candidate; OEM reviewed; stock checked 2026-10-10; not production-qualified | 1uF_AVDD2 | Fitted
C66 | 1 | 1uF | FH(风华) | 0603B105K250NT | Capacitor_SMD:C_0603_1608Metric | C59302 | CL10B105KA8NNNC | C29936 | BLOCKED_ZERO_STOCK | Prototype candidate; OEM reviewed; stock checked 2026-10-10; not production-qualified | 1uF_AVDD3 | Fitted
C67 | 1 | 1uF | FH(风华) | 0603B105K250NT | Capacitor_SMD:C_0603_1608Metric | C59302 | CL10B105KA8NNNC | C29936 | BLOCKED_ZERO_STOCK | Prototype candidate; OEM reviewed; stock checked 2026-10-10; not production-qualified | 1uF_AVDD4 | Fitted
C68 | 1 | 1uF | FH(风华) | 0603B105K250NT | Capacitor_SMD:C_0603_1608Metric | C59302 | CL10B105KA8NNNC | C29936 | BLOCKED_ZERO_STOCK | Prototype candidate; OEM reviewed; stock checked 2026-10-10; not production-qualified | 1uF_DVDD | Fitted
C69 | 1 | 10uF | HRE(芯声) | CGA1206X7R106K250NT | Capacitor_SMD:C_1206_3216Metric | C6119987 | CC1206KKX7R8BB106 | C70462 | READY_FOR_PROTOTYPE | Prototype candidate; OEM reviewed; stock checked 2026-10-10; not production-qualified | 10uF_25V_DRV | Fitted
C70 | 1 | 100nF | FH(风华) | 0603B104K500NT | Capacitor_SMD:C_0603_1608Metric | C30926 | CL10B104KB8NNNC | C1591 | READY_FOR_PROTOTYPE | Prototype candidate; OEM reviewed; stock checked 2026-10-10; not production-qualified | 100nF_VIO | Fitted
C71 | 1 | 4.7uF | HRE(芯声) | CGA0805X7R475K250MT | Capacitor_SMD:C_0805_2012Metric | C6119942 | CL21B475KOFNNNE | C107365 | READY_FOR_PROTOTYPE | Prototype candidate; OEM reviewed; stock checked 2026-10-10; not production-qualified | 4.7uF_VIO | Fitted
C80 | 1 | 100nF | FH(风华) | 0603B104K500NT | Capacitor_SMD:C_0603_1608Metric | C30926 | CL10B104KB8NNNC | C1591 | READY_FOR_PROTOTYPE | Prototype candidate; OEM reviewed; stock checked 2026-10-10; not production-qualified | See schematic | Fitted
C81 | 1 | 100nF | FH(风华) | 0603B104K500NT | Capacitor_SMD:C_0603_1608Metric | C30926 | CL10B104KB8NNNC | C1591 | READY_FOR_PROTOTYPE | Prototype candidate; OEM reviewed; stock checked 2026-10-10; not production-qualified | See schematic | Fitted
C82 | 1 | 100nF | FH(风华) | 0603B104K500NT | Capacitor_SMD:C_0603_1608Metric | C30926 | CL10B104KB8NNNC | C1591 | READY_FOR_PROTOTYPE | Prototype candidate; OEM reviewed; stock checked 2026-10-10; not production-qualified | See schematic | Fitted
C83 | 1 | 100nF | FH(风华) | 0603B104K500NT | Capacitor_SMD:C_0603_1608Metric | C30926 | CL10B104KB8NNNC | C1591 | READY_FOR_PROTOTYPE | Prototype candidate; OEM reviewed; stock checked 2026-10-10; not production-qualified | See schematic | Fitted
C84 | 1 | 100nF | FH(风华) | 0603B104K500NT | Capacitor_SMD:C_0603_1608Metric | C30926 | CL10B104KB8NNNC | C1591 | READY_FOR_PROTOTYPE | Prototype candidate; OEM reviewed; stock checked 2026-10-10; not production-qualified | See schematic | Fitted
C85 | 1 | 100nF | FH(风华) | 0603B104K500NT | Capacitor_SMD:C_0603_1608Metric | C30926 | CL10B104KB8NNNC | C1591 | READY_FOR_PROTOTYPE | Prototype candidate; OEM reviewed; stock checked 2026-10-10; not production-qualified | See schematic | Fitted
C86 | 1 | 100nF | FH(风华) | 0603B104K500NT | Capacitor_SMD:C_0603_1608Metric | C30926 | CL10B104KB8NNNC | C1591 | READY_FOR_PROTOTYPE | Prototype candidate; OEM reviewed; stock checked 2026-10-10; not production-qualified | See schematic | Fitted
C87 | 1 | 100nF | FH(风华) | 0603B104K500NT | Capacitor_SMD:C_0603_1608Metric | C30926 | CL10B104KB8NNNC | C1591 | READY_FOR_PROTOTYPE | Prototype candidate; OEM reviewed; stock checked 2026-10-10; not production-qualified | See schematic | Fitted
C88 | 1 | 100nF | FH(风华) | 0603B104K500NT | Capacitor_SMD:C_0603_1608Metric | C30926 | CL10B104KB8NNNC | C1591 | READY_FOR_PROTOTYPE | Prototype candidate; OEM reviewed; stock checked 2026-10-10; not production-qualified | See schematic | Fitted
C89 | 1 | 100nF | FH(风华) | 0603B104K500NT | Capacitor_SMD:C_0603_1608Metric | C30926 | CL10B104KB8NNNC | C1591 | READY_FOR_PROTOTYPE | Prototype candidate; OEM reviewed; stock checked 2026-10-10; not production-qualified | See schematic | Fitted
C90 | 1 | 100nF | FH(风华) | 0603B104K500NT | Capacitor_SMD:C_0603_1608Metric | C30926 | CL10B104KB8NNNC | C1591 | READY_FOR_PROTOTYPE | Prototype candidate; OEM reviewed; stock checked 2026-10-10; not production-qualified | See schematic | Fitted
C91 | 1 | 100nF | FH(风华) | 0603B104K500NT | Capacitor_SMD:C_0603_1608Metric | C30926 | CL10B104KB8NNNC | C1591 | READY_FOR_PROTOTYPE | Prototype candidate; OEM reviewed; stock checked 2026-10-10; not production-qualified | See schematic | Fitted
C92 | 1 | 1nF | FH(风华) | 0603CG102J101NT | Capacitor_SMD:C_0603_1608Metric | C88489 | CL10C102JB8NNNC | C163508 | READY_FOR_PROTOTYPE | Prototype candidate; OEM reviewed; stock checked 2026-10-10; not production-qualified | See schematic | Fitted
C93 | 1 | 100nF | FH(风华) | 0603B104K500NT | Capacitor_SMD:C_0603_1608Metric | C30926 | CL10B104KB8NNNC | C1591 | READY_FOR_PROTOTYPE | Prototype candidate; OEM reviewed; stock checked 2026-10-10; not production-qualified | See schematic | Fitted
C94 | 1 | 100nF | Murata | GRT31C5C1H104FA02L | Capacitor_SMD:C_1206_3216Metric | C3839854 | C3216C0G1H104JT000N | C319186 | CONDITIONAL_TIMING_REBUDGET_NOT_1PCT_EQUIVALENT | OPEN | TPS3890 reset recovery; CT 100nF; C0G or qualified stable effective capacitance | Fitted
CBOOT1 | 1 | 470nF | FH(风华) | 0805B474K500NT | Capacitor_SMD:C_0805_2012Metric | C49955 | 0805B474K500CT-C | C2991505 | Prototype alternative; Walsin; DC-bias qualification OPEN | Prototype candidate; stock checked 2026-10-10; bootstrap effective capacitance OPEN | 470nF_50V_X7R_10%; effective capacitance and refresh qualification OPEN | Fitted
CBOOT2 | 1 | 470nF | FH(风华) | 0805B474K500NT | Capacitor_SMD:C_0805_2012Metric | C49955 | 0805B474K500CT-C | C2991505 | Prototype alternative; Walsin; DC-bias qualification OPEN | Prototype candidate; stock checked 2026-10-10; bootstrap effective capacitance OPEN | 470nF_50V_X7R_10%; effective capacitance and refresh qualification OPEN | Fitted
CBOOT3 | 1 | 470nF | FH(风华) | 0805B474K500NT | Capacitor_SMD:C_0805_2012Metric | C49955 | 0805B474K500CT-C | C2991505 | Prototype alternative; Walsin; DC-bias qualification OPEN | Prototype candidate; stock checked 2026-10-10; bootstrap effective capacitance OPEN | 470nF_50V_X7R_10%; effective capacitance and refresh qualification OPEN | Fitted
D1 | 1 | SMCJ54A | TBD | TBD | Diode_SMD:D_SMC | UNVERIFIED | UNQUALIFIED | UNVERIFIED | OPEN | OPEN | SMCJ54A_DNP_VERIFY_CLAMP | DNP; populate only after option review; exact MPN / rating qualification open
F1 | 1 | 25A_0456025.ER | Littelfuse | 0456025.ER | fpga-servo:Littelfuse_456_25A_SMD | C315877 | UNQUALIFIED | UNVERIFIED | OPEN | China stock2574 checked2026-10-10;critical protection single-source exception;coordinationOPEN | ONBOARD SMD25A very-fast;500A@72VDC;bus<=72V and prospectivefault<=500A qualificationOPEN | Fitted
F2 | 1 | 0.5A_PTC_ENCODER_5V | JDTfuse(集电通) | ASMD1812-050 | Fuse:Fuse_1812_4532Metric | C135358 | MF-MSMF050-2 | C17313 | CONDITIONAL: Bourns OEM land differs; ambient<=85C and derated hold current validation | China stock2790 checked2026-10-10; local ambient<=85C; hold0.45A at40C; Bourns alternate land review required | See schematic | Fitted
J1 | 1 | AX7010_PL_A | JILN(锦凌) | 321040SG0ABK00A01 | fpga-servo:JILN_3210_2x20_P2.54mm_D1.02 | C601944 | 2.54-2*20P直简牛 | C9138 | {\"status\": \"CONDITIONAL_CURRENT_AND_OEM_PROVENANCE_REVIEW\", \"family_pdf\": \"/private/tmp/passive-oem/9661.pdf\", \"origin\": \"Mainland China\", \"ratings\": \"1A,-55..105C,contact30mohmmax; not3Aequivalent\", \"land\": \"2.54pitch2rows,1.0finishedholes,0.64squarepins; samecopperpattern\", \"body\": \"L=2.54*n+7.6±.5;width9.0±.1;height8.8±.1;keywidth4.5±.1;tail3.3±.1\", \"provenance\": \"ChineseC9138page suppliesfamilydrawing 简牛2.54-2xnP(3<=n<=40), supplier栏blank; C5665page hasnoPDF. Mechanicalfamilyevidence exists but exactmanufacturerattestationnotproven.\", \"current_application\": \"J5 .5A PTC limits demand; J1 per-pin demand<1A required, system load qualification open.\"} | China stock verified 2026-10-10; BOOMELE alternate conditional <=1A/pin and manufacturer drawing confirmation; finished holes 1.02+/-0.03mm | See schematic | Fitted
J3 | 1 | DC_IN_48V | Phoenix Contact(菲尼克斯) | 1714971 | fpga-servo:PhoenixContact_MKDS_5_2_9.52mm | C92145 | UNQUALIFIED | UNVERIFIED | OPEN | Existing critical part retained; single-source exception; stock checked 2026-10-10 | DC input; J3.1 VIN_RAW then onboard F1 then VIN_FUSED to Q7 | Fitted
J4 | 1 | MOTOR_UVW | KEFA | KF950-9.5-3P | fpga-servo:KEFA_KF950_3_9.50mm | C475107 | UNQUALIFIED | UNVERIFIED | Megastar ZX-DG10-9.5-3P requires different hole/body; NOT drop-in | China stock200 checked2026-10-10; OEM land reviewed; 32A IEC rating; mechanical/current/thermal qualification OPEN; critical power connector single-source exception | MKDS_5_3_9.5_32A_motor_terminal | Fitted
J5 | 1 | ABZ_DIFF_ENCODER | JILN(锦凌) | 321010SG0ABK00A01 | fpga-servo:JILN_3210_2x05_P2.54mm_D1.02 | C429962 | 2.54-2*5P简牛 | C5665 | {\"status\": \"CONDITIONAL_CURRENT_AND_OEM_PROVENANCE_REVIEW\", \"family_pdf\": \"/private/tmp/passive-oem/9661.pdf\", \"origin\": \"Mainland China\", \"ratings\": \"1A,-55..105C,contact30mohmmax; not3Aequivalent\", \"land\": \"2.54pitch2rows,1.0finishedholes,0.64squarepins; samecopperpattern\", \"body\": \"L=2.54*n+7.6±.5;width9.0±.1;height8.8±.1;keywidth4.5±.1;tail3.3±.1\", \"provenance\": \"ChineseC9138page suppliesfamilydrawing 简牛2.54-2xnP(3<=n<=40), supplier栏blank; C5665page hasnoPDF. Mechanicalfamilyevidence exists but exactmanufacturerattestationnotproven.\", \"current_application\": \"J5 .5A PTC limits demand; J1 per-pin demand<1A required, system load qualification open.\"} | China stock verified 2026-10-10; BOOMELE alternate conditional <=1A/pin and manufacturer drawing confirmation; finished holes 1.02+/-0.03mm | See schematic | Fitted
J6 | 1 | PSU_EXT | System interface | TBD |  | UNVERIFIED | UNQUALIFIED | UNVERIFIED | OPEN | OPEN | External PSU output reference only; no external fuse holder; onboard F1 protects downstream board | External; NOT fitted to PCB; exact MPN / rating qualification open
L1 | 1 | 68uH | SOREDE | SDRH.1209.LF680MT00 | fpga-servo:SOREDE_SDRH1209_68uH | C2942326 | UNQUALIFIED | UNVERIFIED | OPEN | Stock55; prototype only; Irms/guaranteed1A/thermal OPEN; critical power single-source exception | 68uH_MSS1246T-683MLC | Fitted
L2 | 1 | 2.2uH | Sunlord | SWPA4020S2R2MT | fpga-servo:Sunlord_SWPA4020S | C83423 | FHD4020S-2R2MT | C602029 | cjiang; same OEM land;2.2uH20%;DCRmax56mOhm Isat6A Irms4A; thermal qualification OPEN | OPEN | 2.2uH_74438356022_WE-MAPI-4020 | Fitted
NTC1 | 1 | 10k | Shiheng | CMFA 103F3950 | fpga-servo:NTC_0603_Shiheng_KUU | C2889049 | KNTC0603/10KF3950 | C2892547 | Different manufacturer KUU; same recommended land and10k1%/B25-50=3950; temperature calibration required | OPEN | 10k_B3950_BOARD | Fitted
NTC2 | 1 | 10k | Shiheng | CMFA 103F3950 | fpga-servo:NTC_0603_Shiheng_KUU | C2889049 | KNTC0603/10KF3950 | C2892547 | Different manufacturer KUU; same recommended land and10k1%/B25-50=3950; temperature calibration required | OPEN | 10k_B3950_MOTOR | Fitted
Q1 | 1 | BSC040N10NS5 | Infineon(英飞凌) | BSC040N10NS5 | Package_SON:Infineon_PG-TDSON-8_6.15x5.15mm | C534334 | UNQUALIFIED | UNVERIFIED | OPEN | Existing critical part retained; single-source exception; stock checked 2026-10-10 | BSC040N10NS5_HS | Fitted
Q2 | 1 | BSC040N10NS5 | Infineon(英飞凌) | BSC040N10NS5 | Package_SON:Infineon_PG-TDSON-8_6.15x5.15mm | C534334 | UNQUALIFIED | UNVERIFIED | OPEN | Existing critical part retained; single-source exception; stock checked 2026-10-10 | BSC040N10NS5_LS | Fitted
Q3 | 1 | BSC040N10NS5 | Infineon(英飞凌) | BSC040N10NS5 | Package_SON:Infineon_PG-TDSON-8_6.15x5.15mm | C534334 | UNQUALIFIED | UNVERIFIED | OPEN | Existing critical part retained; single-source exception; stock checked 2026-10-10 | BSC040N10NS5_HS | Fitted
Q4 | 1 | BSC040N10NS5 | Infineon(英飞凌) | BSC040N10NS5 | Package_SON:Infineon_PG-TDSON-8_6.15x5.15mm | C534334 | UNQUALIFIED | UNVERIFIED | OPEN | Existing critical part retained; single-source exception; stock checked 2026-10-10 | BSC040N10NS5_LS | Fitted
Q5 | 1 | BSC040N10NS5 | Infineon(英飞凌) | BSC040N10NS5 | Package_SON:Infineon_PG-TDSON-8_6.15x5.15mm | C534334 | UNQUALIFIED | UNVERIFIED | OPEN | Existing critical part retained; single-source exception; stock checked 2026-10-10 | BSC040N10NS5_HS | Fitted
Q6 | 1 | BSC040N10NS5 | Infineon(英飞凌) | BSC040N10NS5 | Package_SON:Infineon_PG-TDSON-8_6.15x5.15mm | C534334 | UNQUALIFIED | UNVERIFIED | OPEN | Existing critical part retained; single-source exception; stock checked 2026-10-10 | BSC040N10NS5_LS | Fitted
Q7 | 1 | BSC040N10NS5 | Infineon(英飞凌) | BSC040N10NS5 | Package_SON:Infineon_PG-TDSON-8_6.15x5.15mm | C534334 | UNQUALIFIED | UNVERIFIED | OPEN | Existing critical part retained; single-source exception; stock checked 2026-10-10 | BSC040N10NS5_RPP_Q7 | Fitted
Q8 | 1 | BSC040N10NS5 | Infineon(英飞凌) | BSC040N10NS5 | Package_SON:Infineon_PG-TDSON-8_6.15x5.15mm | C534334 | UNQUALIFIED | UNVERIFIED | OPEN | Existing critical part retained; single-source exception; stock checked 2026-10-10 | BSC040N10NS5_RPP_Q8 | Fitted
R1 | 1 | 280k | RESI(开步睿思) | PTFR0805B280KP9 | Resistor_SMD:R_0805_2012Metric | C2849140 | RT0805BRD07280KL | C865351 | READY_FOR_PROTOTYPE | Prototype candidate; OEM reviewed; stock checked 2026-10-10; not production-qualified | 280k_0.1% | Fitted
R2 | 1 | 280k | RESI(开步睿思) | PTFR0805B280KP9 | Resistor_SMD:R_0805_2012Metric | C2849140 | RT0805BRD07280KL | C865351 | READY_FOR_PROTOTYPE | Prototype candidate; OEM reviewed; stock checked 2026-10-10; not production-qualified | 280k_0.1% | Fitted
R3 | 1 | 39k | UNI-ROYAL(厚声) | TC0325B3902T5F | Resistor_SMD:R_0603_1608Metric | C2988897 | RT0603BRD0739KL | C309652 | READY_FOR_PROTOTYPE | Prototype candidate; OEM reviewed; stock checked 2026-10-10; not production-qualified | 39k_0.1% | Fitted
R20 | 1 | 100k | UNI-ROYAL(厚声) | 0603WAF1003T5E | Resistor_SMD:R_0603_1608Metric | C25803 | RS-03K1003FT | C115320 | READY_FOR_LOW_VOLTAGE_REFS_ONLY_R20_BLOCKED | Prototype candidate; OEM reviewed; stock checked 2026-10-10; not production-qualified | 100k_RON_1% | Fitted
R21 | 1 | 453k | YAGEO(国巨) | RC0603FR-07453KL | Resistor_SMD:R_0603_1608Metric | C273765 | RTT034533FTP | C103651 | BLOCKED_NOT_SOURCED_OR_NO_STOCK | Prototype candidate; OEM reviewed; stock checked 2026-10-10; not production-qualified | 453k_RFB1_1% | Fitted
R22 | 1 | 49.9k | UNI-ROYAL(厚声) | 0603WAF4992T5E | Resistor_SMD:R_0603_1608Metric | C23184 | RT0603BRD0749K9L | C705780 | READY_FOR_PROTOTYPE | Prototype candidate; OEM reviewed; stock checked 2026-10-10; not production-qualified | 49.9k_RFB2_1% | Fitted
R23 | 1 | 453k | YAGEO(国巨) | RC0603FR-07453KL | Resistor_SMD:R_0603_1608Metric | C273765 | RTT034533FTP | C103651 | BLOCKED_NOT_SOURCED_OR_NO_STOCK | Prototype candidate; OEM reviewed; stock checked 2026-10-10; not production-qualified | 453k_RA_1% | Fitted
R32 | 1 | 100k | TBD | TBD | Resistor_SMD:R_0603_1608Metric | UNVERIFIED | UNQUALIFIED | UNVERIFIED | OPEN | OPEN | 100k_PG_PULLUP_DNP | DNP; populate only after option review; exact MPN / rating qualification open
R40 | 1 | 47R | FH(风华) | RS-03K47R0FT | Resistor_SMD:R_0603_1608Metric | C140087 | 0603WAF470JT5E | C23182 | READY_FOR_PROTOTYPE | Prototype candidate; OEM reviewed; stock checked 2026-10-10; not production-qualified | 47R_ADC_ISOLATION | Fitted
R41 | 1 | 47R | FH(风华) | RS-03K47R0FT | Resistor_SMD:R_0603_1608Metric | C140087 | 0603WAF470JT5E | C23182 | READY_FOR_PROTOTYPE | Prototype candidate; OEM reviewed; stock checked 2026-10-10; not production-qualified | 47R_ADC_ISOLATION | Fitted
R42 | 1 | 47R | FH(风华) | RS-03K47R0FT | Resistor_SMD:R_0603_1608Metric | C140087 | 0603WAF470JT5E | C23182 | READY_FOR_PROTOTYPE | Prototype candidate; OEM reviewed; stock checked 2026-10-10; not production-qualified | 47R_ADC_ISOLATION | Fitted
R50 | 1 | 8.2k | RESI(开步睿思) | PTFR0603B8K20P9 | Resistor_SMD:R_0603_1608Metric | C351624 | RT0603BRD078K2L | C861589 | READY_FOR_PROTOTYPE | Prototype candidate; OEM reviewed; stock checked 2026-10-10; thermal and dynamic qualification OPEN | Bus OCP divider; nominal 1.000V at VA_5V=5.1V | Fitted
R53 | 1 | 2k | FH(风华) | TD03G2001BT | Resistor_SMD:R_0603_1608Metric | C666953 | ERA3AEB202V | C193242 | READY_FOR_PROTOTYPE | Prototype candidate; OEM reviewed; stock checked 2026-10-10; thermal and dynamic qualification OPEN | Bus OCP divider; nominal 1.000V at VA_5V=5.1V | Fitted
R54 | 1 | 4.7k | FH(风华) | RS-03K4701FT | Resistor_SMD:R_0603_1608Metric | C116693 | 0603WAF4701T5E | C23162 | READY_FOR_PROTOTYPE | Prototype candidate; OEM reviewed; stock checked 2026-10-10; not production-qualified | 4.7k_OCP_PULLUP_TO_VIO | Fitted
R55 | 1 | 10k | FH(风华) | ABD03K1002FT | Resistor_SMD:R_0603_1608Metric | C5139509 | 0603WAF1002T5E | C25804 | READY_FOR_PROTOTYPE | Prototype candidate; OEM reviewed; stock checked 2026-10-10; not production-qualified | 10k_PWR_GOOD_PULLUP | Fitted
R56 | 1 | 100k | FH(风华) | RS-03K1003FT | Resistor_SMD:R_0603_1608Metric | C115320 | 0603WAF1003T5E | C25803 | READY_FOR_LOW_VOLTAGE_REFS_ONLY_R20_BLOCKED | Prototype candidate; OEM reviewed; stock checked 2026-10-10; not production-qualified | 100k_PWM_INPUT_PULLDOWN | Fitted
R57 | 1 | 100k | FH(风华) | RS-03K1003FT | Resistor_SMD:R_0603_1608Metric | C115320 | 0603WAF1003T5E | C25803 | READY_FOR_LOW_VOLTAGE_REFS_ONLY_R20_BLOCKED | Prototype candidate; OEM reviewed; stock checked 2026-10-10; not production-qualified | 100k_PWM_INPUT_PULLDOWN | Fitted
R58 | 1 | 100k | FH(风华) | RS-03K1003FT | Resistor_SMD:R_0603_1608Metric | C115320 | 0603WAF1003T5E | C25803 | READY_FOR_LOW_VOLTAGE_REFS_ONLY_R20_BLOCKED | Prototype candidate; OEM reviewed; stock checked 2026-10-10; not production-qualified | 100k_PWM_INPUT_PULLDOWN | Fitted
R59 | 1 | 100k | FH(风华) | RS-03K1003FT | Resistor_SMD:R_0603_1608Metric | C115320 | 0603WAF1003T5E | C25803 | READY_FOR_LOW_VOLTAGE_REFS_ONLY_R20_BLOCKED | Prototype candidate; OEM reviewed; stock checked 2026-10-10; not production-qualified | 100k_PWM_INPUT_PULLDOWN | Fitted
R60 | 1 | 100k | FH(风华) | RS-03K1003FT | Resistor_SMD:R_0603_1608Metric | C115320 | 0603WAF1003T5E | C25803 | READY_FOR_LOW_VOLTAGE_REFS_ONLY_R20_BLOCKED | Prototype candidate; OEM reviewed; stock checked 2026-10-10; not production-qualified | 100k_PWM_INPUT_PULLDOWN | Fitted
R61 | 1 | 100k | FH(风华) | RS-03K1003FT | Resistor_SMD:R_0603_1608Metric | C115320 | 0603WAF1003T5E | C25803 | READY_FOR_LOW_VOLTAGE_REFS_ONLY_R20_BLOCKED | Prototype candidate; OEM reviewed; stock checked 2026-10-10; not production-qualified | 100k_PWM_INPUT_PULLDOWN | Fitted
R70 | 1 | 10k | FH(风华) | TD03G1002BT | Resistor_SMD:R_0603_1608Metric | C667034 | PTFR0603B10K0P9 | C328421 | READY_FOR_PROTOTYPE | Prototype candidate; OEM reviewed; stock checked 2026-10-10; not production-qualified | 10k_0.1%_NTC_PULLUP | Fitted
R71 | 1 | 10k | FH(风华) | TD03G1002BT | Resistor_SMD:R_0603_1608Metric | C667034 | PTFR0603B10K0P9 | C328421 | READY_FOR_PROTOTYPE | Prototype candidate; OEM reviewed; stock checked 2026-10-10; not production-qualified | 10k_0.1%_NTC_PULLUP | Fitted
R80 | 1 | 10k | FH(风华) | ABD03K1002FT | Resistor_SMD:R_0603_1608Metric | C5139509 | 0603WAF1002T5E | C25804 | READY_FOR_PROTOTYPE | Prototype candidate; OEM reviewed; stock checked 2026-10-10; not production-qualified | See schematic | Fitted
R81 | 1 | 10k | FH(风华) | ABD03K1002FT | Resistor_SMD:R_0603_1608Metric | C5139509 | 0603WAF1002T5E | C25804 | READY_FOR_PROTOTYPE | Prototype candidate; OEM reviewed; stock checked 2026-10-10; not production-qualified | See schematic | Fitted
R82 | 1 | 10k | FH(风华) | ABD03K1002FT | Resistor_SMD:R_0603_1608Metric | C5139509 | 0603WAF1002T5E | C25804 | READY_FOR_PROTOTYPE | Prototype candidate; OEM reviewed; stock checked 2026-10-10; not production-qualified | See schematic | Fitted
R83 | 1 | 10k | FH(风华) | ABD03K1002FT | Resistor_SMD:R_0603_1608Metric | C5139509 | 0603WAF1002T5E | C25804 | READY_FOR_PROTOTYPE | Prototype candidate; OEM reviewed; stock checked 2026-10-10; not production-qualified | See schematic | Fitted
R84 | 1 | 10k | FH(风华) | ABD03K1002FT | Resistor_SMD:R_0603_1608Metric | C5139509 | 0603WAF1002T5E | C25804 | READY_FOR_PROTOTYPE | Prototype candidate; OEM reviewed; stock checked 2026-10-10; not production-qualified | See schematic | Fitted
R85 | 1 | 10k | FH(风华) | ABD03K1002FT | Resistor_SMD:R_0603_1608Metric | C5139509 | 0603WAF1002T5E | C25804 | READY_FOR_PROTOTYPE | Prototype candidate; OEM reviewed; stock checked 2026-10-10; not production-qualified | See schematic | Fitted
R86 | 1 | 10k | FH(风华) | ABD03K1002FT | Resistor_SMD:R_0603_1608Metric | C5139509 | 0603WAF1002T5E | C25804 | READY_FOR_PROTOTYPE | Prototype candidate; OEM reviewed; stock checked 2026-10-10; not production-qualified | See schematic | Fitted
R87 | 1 | 10k | FH(风华) | ABD03K1002FT | Resistor_SMD:R_0603_1608Metric | C5139509 | 0603WAF1002T5E | C25804 | READY_FOR_PROTOTYPE | Prototype candidate; OEM reviewed; stock checked 2026-10-10; not production-qualified | See schematic | Fitted
R88 | 1 | 1k | FH(风华) | ABD03K1001FT | Resistor_SMD:R_0603_1608Metric | C5125843 | CRCW06031K00FKEA | C844920 | CANDIDATE_OEM_REVIEW_PENDING | Prototype candidate; OEM reviewed; stock checked 2026-10-10; not production-qualified | See schematic | Fitted
R89 | 1 | 100k | FH(风华) | RS-03K1003FT | Resistor_SMD:R_0603_1608Metric | C115320 | 0603WAF1003T5E | C25803 | READY_FOR_LOW_VOLTAGE_REFS_ONLY_R20_BLOCKED | Prototype candidate; OEM reviewed; stock checked 2026-10-10; not production-qualified | See schematic | Fitted
R90 | 1 | 10k | FH(风华) | ABD03K1002FT | Resistor_SMD:R_0603_1608Metric | C5139509 | 0603WAF1002T5E | C25804 | READY_FOR_PROTOTYPE | Prototype candidate; OEM reviewed; stock checked 2026-10-10; not production-qualified | See schematic | Fitted
R91 | 1 | 10k | FH(风华) | ABD03K1002FT | Resistor_SMD:R_0603_1608Metric | C5139509 | 0603WAF1002T5E | C25804 | READY_FOR_PROTOTYPE | Prototype candidate; OEM reviewed; stock checked 2026-10-10; not production-qualified | See schematic | Fitted
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

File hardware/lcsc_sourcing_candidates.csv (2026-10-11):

Ref group | Target MPN | LCSC C-code | Role | Schematic status | PCB status | Procurement status | Safety note
U2 U3 U4 | INA240A1DR | C2060769 | Current sense 20 V/V | Implemented | Value-only same physical lands | Stock shown; recheck order | 80V common-mode not qualified
U15 U16 | LM339LVPWR | C3658338 | Open-drain quad comparator | Implemented | Value-only same physical lands | Stock shown; recheck order | Delay/OCP not qualified
RSH1 RSH2 RSH3 | LR2512-23R005F4 | C154688 | 5mR 3W 2512 2-terminal shunt | PROPOSAL ONLY | NOT IMPLEMENTED; legacy 4-terminal holes | Stock shown; recheck order | PROHIBIT_FAB until Kelvin + thermal redesign
Q1 to Q8 | BSC040N10NS5ATMA1 |  | Power MOSFET | Original retained | Original retained | Manufacturer-grade procurement pending | Non-original-name alternatives require gate charge SOA thermal qualification
U1 | FD6288T | C97683 | Gate driver | Original retained | Original retained | Stock shown; recheck order | Critical keep actual vendor

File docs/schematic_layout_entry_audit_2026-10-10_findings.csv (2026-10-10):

id | severity | kind | stage | component | source | issue | evidence | risk | next_action | acceptance | status
S01 | P0 | 已确认设计缺口 | 正式 layout 前关闭 | U25/U6/U20/U11 | ocp_latch / current_adc | ADC 模拟供电失效区仍可能允许 PWM | 新网表：U25.5=VA_5V，U25.6=VIO_3V3；U25 为 TPS3808G50。ADS8588S AVDD 下限 4.75V；G50 全温保守下降阈值 4.557..4.743V，-40..85°C 为 4.58025..4.71975V。无独立 ADC_VALID 硬件许可。来源 [D1][D2]、qualification.json。 | VA5 下降时 ADC 可先失去规定精度/功能，而 ARMED/RUN_OK 尚未保证关闭。独立模拟 OCP 的存在不能证明采样闭环仍正确。7mV 只是采用最早动作角点时的最小窗口，典型约100mV，不能当成最坏窗口。 | 优先设计覆盖 ADC 工作下限的硬件许可/监督，并把它纳入门控和故障锁存；阈值须计入检测误差、迟滞、纹波、下降速率和检测到 VGS 关闭的总时延，不直接照抄4.75V标称。 | 提供可满足“最迟关断时 ADC 仍有效”的最坏角点计算；新网表证明无效许可能异步关断并锁存。下降/上升、慢坡/快速跌落、随机上电次序和 CLEAR 竞争先做适用模型验证，样机再实测。 | OPEN
S02 | P1 | 已确认保护覆盖缺口 | 正式功率布局前确定保护架构 | Q1..Q6/RSH1..3/F1 | gate_inverter / power_input | 相电流 OCP 不覆盖桥臂内部直通故障电流 | U相：Q1.5=VBUS_PROT，Q1.1..3=Q2.5=SW_U，Q2.1..3=GND；RSH1 串在 SW_U 与 PH_U 间。V/W 同理。analysis.json 保存三条路径证明。 | VBUS_PROT→上管→下管→GND 绕过相 shunt；正常命令互锁不覆盖 MOSFET 短路等故障。源端 F1 也不在板上 DC-link 电容局部放电路径中。此项不表示正常 PWM 必然直通。 | 编制电机过载、相线短路、上下管/门驱故障、母线短路覆盖矩阵；对必须覆盖的故障选定独立母线/器件电流检测和快速关断/能量限制方案。不能仅以 FPGA 死区或25A保险视为闭合；若依赖系统限能，须证明能约束板载电容及源侧能量。 | 每类故障列出被检测电流路径、执行器、最坏能量与允许器件应力；需要增加的检测/关断元件在功率铜和连接器布局前落实。样机破坏性短路试验不属于本次审计。 | OPEN
S03 | P1 | 已确认拓扑＋系统证据缺口 | 正式功率布局前确定方案；投板前完成额定验证 | D1/U18/C1/C2/Q7/Q8 | power_input | 回馈吸收及正向过压保护未闭合 | D1=SMCJ54A 且 dnp；U18.7(OV)=GND；C1+C2=200uF。LM74502 只做反接、无反向电流阻断，VS 推荐最高60V/绝对最高65V。spice/results.json：理想无吸收1A由48到55V需1.4ms。来源[D3]。 | 回馈或输入浪涌可能超过控制器/下游器件范围。200uF 不是已合格制动器；55V 是演示值，不是安全上限。即使把D1装上，也必须校验动态钳位电压、源端U18所处位置和能量。 | 冻结电源可回充能力、最大机械/感性能量及断电状态；优先明确系统回馈吸收/制动及源侧浪涌保护边界，再决定板载OV、钳位及预留接口。不能只把D1改成装配。 | 用实际能量、源阻抗和线缆寄生证明各节点低于其带裕量工作限值；钳位/制动元件能量、温升和故障状态有计算，拓扑和必要封装在功率布局前确定。 | OPEN
S04 | P1 | 动态资格缺口 | 布局冻结前有设计界限；样机功率试验前实测 | U2..4/U15/U16/U26/U23/U20/U11/U8..10/U1/Q1..6 | current_adc / ocp_latch / gate_inverter | 全链路 OCP 延迟与 MOSFET SOA 未建立最坏界限 | 实际路径为 INA→47Ω/1nF→TLV9024开漏→U26→U23/U20→U11/U8..10→FD6288→MOSFET。531项回归仅稳态布尔行为。TLV9024速度典型值、FD6288 25°C/15V时序、Qg/峰值电流比均不能成为本工况全温保证。来源[D4][D5][D6][D7]。 | 高 di/dt 故障在关断前可能超过器件应力；相电流正好越阈值时的低过驱会影响延迟。数字32ns预算不是从故障发生到VGS关闭的上界。 | 按故障斜率、INA恢复、比较器过驱和开漏RC、逻辑负载、栅阻与温度建立分项预算；核对驱动器保证条件和MOS SOA，缺失保证值时留为未证明，不用典型值补齐。 | 布局前确定所需最短保护路径、测试点和寄生约束；冻结前有受约束的设计预算，样机低能量验证真实电流/OCP_N/六路VGS并校正预算。 | OPEN
S05 | P1 | 规格缺口 | 正式功率布局前关闭 | 整机/Q1..8/RSH1..3/J3/J4 | system / design_calculations | 峰值、10A定义、环境与散热尚未冻结 | 本次授权基线24..48V/20kHz/10A连续相电流；10Arms仅用于计算。未给出峰值及持续时间、最高环境、冷却/机壳、最大电机能量。 | 铜厚/铜面积、端子、shunt、MOSFET、保护阈值和制动设计无法得到一致最坏工况。不能沿用历史15A连续或25A/5s作为已确认要求。 | 形成唯一额定规格表并计算正常峰值、保护阈值、母线电流、热及能量包络。优先锁定会改变器件尺寸和功率布线的项目。 | 规格有可追溯确认；保护阈值在全部误差下高于允许工作电流且低于允许故障应力；热预算据此重算。 | OPEN
S06 | P1 | 选型资格缺口 | 关键封装/额定件在正式相关区域 layout 前；其余投板前 | C1..4/C20..23/C30..31/CBOOT1..3/F2/NTC1..2/D2..4/J1/J2/J5及相关R | BOM / all sheets | 120项 MPN 为 TBD，关键无源及接口额定条件未冻结 | 新系统网表159对象、BOM159行，值/封装/MPN字段无差异；120对象MPN缺失，包括外部J6及非关键被动件，不能把120全部算成电气错误。全部23颗IC、8颗MOSFET已有型号字段。component_inventory.csv可逐项筛选。 | 电容有效容量/ESR/纹波、分压电阻耐压/TCR、PTC动作与阻值、NTC曲线、二极管恢复和连接器额定值无法由名义值及通用封装证明。C3描述FILM但指向通用1210尤其需采购可实现性核验。 | 先冻结影响机械或安全的电容、bootstrap二极管/PTC/连接器及精密阈值电阻；普通电阻可按明确容差、功率、耐压、TCR的受控替代表管理，不强求每颗先指定唯一厂家。 | 关键器件准确订货码或受控规格可追溯，额定及DC偏压/温度降额满足计算，封装与采购实物一致；不得仅清空TBD字符串。 | OPEN
S07 | P1 | 应用资格缺口 | 正式驱动布局前完成设计计算；冻结前动态验证 | U1/D2..4/CBOOT1..3/RG1..6/RGS1..6 | gate_inverter | Bootstrap、最长高侧保持及死区未与实际工况配合 | 新网表D2..4 K1→BST，A2→12V，CBOOT=1uF跨BST/SW；RG=10Ω，RGS=10k。FD6288 V1.6 p4/10..14有自举、UVLO、互锁和死区条件；内部死区100..300ns为25°C/15V条件。资料[D6]为本地厂商缓存。 | 1uF标称不等于有效容量；高侧10k栅源电阻本身持续耗用bootstrap电荷，不能只算Qg。无刷新下不能保证无限期100%高侧导通；内部互锁不自动证明实际MOSFET交越安全。 | 用有效C、Qg、VGS/RGS、IQBS、漏电与二极管压降计算最低VBS、最大保持和最低刷新；定义预充、PWM最小脉宽/最大占空比及外部死区。复核ES1J准确型号和恢复；厂商偏好Schottky不等于ES1J必然错误。 | 最坏VBS及VGS同时满足驱动和MOS导通要求；时序预算覆盖真实温度/负载，预充和刷新协议写入接口要求；六路波形在样机低能量阶段验证。 | OPEN
S08 | P1 | 负载/稳压资格缺口 | 正式电源区域 layout 前完成预算；投板前验证 | U12/U13/L1/L2/C20..31/J5/F2 | aux_power / encoder | 辅助电源拓扑正确，但全负载、启动及有效容量预算未闭合 | LM5164外围与原厂12V/1A/300kHz示例同类；TPS62163为固定5V，FB接GND/VOS接5V。L1=MSS1246T-683MLC，L2=74438356022，5V还直接供编码器。来源[D8][D9][D14][D15]。 | 1A芯片额定不等于编码器可取1A；编码器短路/启动可拖低ADC/OCP电源。磁件热、电容DC偏压和启动时MOS栅极状态未被理想RC仿真覆盖。 | 分别预算12V门驱＋5V转换输入、5V ADC/INA/比较器＋编码器、VIO逻辑；纳入效率、浪涌及PTC慢动作。计算纹波/峰值并按真实电容和电感降额核验，必要时改变编码器供电隔离/限流策略。 | 三轨最坏负载有余量，最低输入/最高温度启动和阶跃满足电压窗口；编码器故障时硬件安全链满足S01/S09。 | OPEN
S09 | P1 | 电源时序资格缺口 | 正式相关区域 layout 前确定策略；样机前完成验证方案 | VIO/VA5/VDRV/U12/U13/U24..26/U6/U1 | aux_power / ocp_latch / current_adc | 部分供电、PGOOD高阻及欠压时的关断/恢复尚无完整证明 | U24/U25均由VIO供电，U25检测VA5；两个buck的开漏PG并网并由VIO上拉。TPS62163关断时PG可高阻。三域八种稳态要求列在power_domain_matrix.csv；全供电仍须健康且有新CLEAR沿。来源[D1][D2][D9]。 | PG高并不单独证明所有模拟域有效；电容残压、短暂掉电及重新恢复可能与锁存状态竞争。Ioff能力或下拉电阻不能替代所有坡形/残压条件的证明。 | 枚举八稳态、六上电/六掉电顺序及毛刺；分析PG关闭条件、残压、门驱UVLO、ADC数字/模拟供电约束和引脚灌电；必要联锁变更在相关区域布局前落实。 | 模型/静态分析清楚区分能证明与未知的组合；任何不允许域组合下六路驱动为低，恢复不自动重新武装。样机测试覆盖真实坡形、极短失电及CLEAR相位。 | OPEN
S10 | P1 | 接口/电源预算缺口 | 接口布局冻结前；实板连续性在连接前 | J1/J2/AX7010/U7/U24 | ax7010_interface / XDC | VIO最低值、负载余量与线缆条件未资格化 | 新网表J1.1/.37/.38=GND，.2=NC，.39/.40=VIO；3..24活跃脚与官方J10表和XDC一致。G33全温保守释放约3.194V。AM26LV32E要求VCC≥3.0V。ALINX公开V2图纸日期2018，不能当成2022实板连续性记录。来源[D1][D10][D16]。 | VIO线缆压降及动态负载可能使监督器不释放或接收器离开规格；信号返回、线缆方向及FPGA位流引脚冲突未实测。 | 确定线缆、方向/防反插、实际AX7010电源可用电流和最小端电压，计算所有VIO负载及逻辑电平裕量；实物逐针确认并按实际Vivado工程核查占用。 | 最坏VIO满足监督恢复、接收器和逻辑条件；J10接线/Bank电压可追溯。接口文档/XDC/实板三者一致，不能把预留XDC端口视为已接线。 | OPEN
S11 | P1 | 接口适配资格缺口 | 正式编码器区域 layout 前确定电气边界 | U7/U19/J5/F2/RT1..3 | encoder | ESD阵列的工作范围未与编码器共模、端接和供电协调 | U19 RVZ14脚序现已正确：IO=14/13/12/11/9/8，GND=5/10。TPD6E05U06建议IO为0..5.5V，AM26LV32E接收共模可达-7..+7V；实际编码器/线缆未知。RT1..3=120Ω DNP，SHIELD脚NC，F2无准确型号。来源[D10][D11]。 | 接收器共模能力不能移植到整个带ESD的端口；超出阵列范围时可能钳位或失真。端接、地偏移和编码器电源短路影响也未定。不能据此断言当前5V编码器一定不能工作。 | 冻结编码器电平/最大频率、共模/地偏移、线缆阻抗和长度；按该包络选择保护、端接装配及屏蔽连接。为F2选定保持/动作电流及热阻曲线，核验共享5V故障行为。 | 端口内每颗器件均覆盖正常/故障电压包络；末端120Ω的装配策略和屏蔽/机壳回路有定义，原理图及BOM同步。 | OPEN
S12 | P1 | 已确认功能定义缺口 | 正式相关区域 layout 前确定 | NTC2/R71/U6.59 | current_adc / architecture | NTC_MOTOR当前没有外部电机测温接口 | NTC_MOTOR只连接R71.2、NTC2.1、U6.59；NTC2为板载0603，所有外部连接器均无该网。架构称CH6为motor/connector NTC。physical_pins.csv与新图面第5页。 | 当前只能测板载NTC2所在位置温度，不能证明测得电机绕组温度；软件命名可能形成错误保护预期。 | 若需要电机外置NTC，增加明确连接器/回流、线缆滤波和ESD、开短路诊断并选定传感器；若只测板/端子温度，则明确收窄功能并更名，不能保留“电机测温已实现”表述。 | 测温对象、物理安装位置、接口和BOM一致；外部方案有开路/短路/热插拔的ADC与保护测试。 | OPEN
S13 | P1 | 封装装配资格缺口 | 相关器件布线冻结前 | U1/U2..4/U6/U12/U13/U18/U19/Q1..8/RSH1..3/J3/J4 | symbols / footprints / PCB | 物理引脚一致性通过，但全部关键land pattern尚未完成装配验收 | 23颗IC型号及关键引脚人工对照厂商资料；所有嵌入与本地库pin-name/type/number无差异。26个关键封装已只读提取。J3/J4为9.52mm节距/1.3mm钻孔；shunt为25.4×6.35mm/2.6mm钻孔，H1孔3.2mm。见board_geometry.json。 | 同名封装、引脚编号相同不能证明焊盘、阻焊/钢网、引脚公差和装配空间完全合格；多处采用通用KiCad IPC焊盘而非原厂样例。 | 对准确订货码逐一签核外形、pin1、EP、焊盘、阻焊/钢网和工艺公差；大端子/shunt核验壳体、钻孔和实物装配。保留已正确的映射，不重新赋占位封装。 | 每类关键封装有尺寸对照、可制造性和装配责任确认；本地shunt/端子有样件或公差链支持，布局保留维修、线束和紧固空间。 | OPEN
S14 | P1 | 已确认PCB基线缺陷 | 正式新增布线前清理；最终DRC在投板前关闭 | 20条遗留铜线/5个zone/全板 | PCB | 旧铜线仍造成真实跨网短路，不能在该状态上直接继续布线 | 新原生DRC：271条=220错误/51警告，478未连接，parity0。分组：clearance113、solder_mask_bridge88、isolated_copper43、shorting_items17、track_dangling8、tracks_crossing2。旧线仍有VBUS/PGND/U_SH_N等旧网名。 | 图板焊盘parity0仅说明预期分配一致，不会消除实际跨网铜短路。现有板不能上电；普通布局移动也不能被视为这些铜已合格。 | 另开PCB修复任务，先保存板快照及机械特征，逐条追踪20条旧线及5个zone，批准后重建失效铜，保留正确网络与机械对象；不得无记录清空所有铜或用排除项消数。 | 旧网铜和17条短路报告逐项闭环后再开始正式新布线；完成板最终要求原生DRC/未连接/parity均0，且没有新增掩盖性忽略。 | OPEN
S15 | P2 | 已确认装配信息不一致 | BOM/接口冻结前 | J2 | ax7010_interface / BOM | J2图面写DNP，但原生属性与BOM为装配 | 第3页标注“J2 unused expansion (DNP)”；新XML无J2 dnp属性，BOM状态Fitted，真实DNP列表只有D1/R32/RT1..3。 | 装配和线缆使用可能与说明不一致；J2电源/地仍连接，不能把图中文字当成有效DNP。 | 统一J2是否装配的政策，在原生dnp属性、BOM和注释中保持一致；若装配，注明信号当前NC及电源连接。 | 新独立BOM/XML/图面三者一致，并保留未使用信号的真实NC状态。 | OPEN
S16 | P2 | 已确认文档版本漂移 | layout交接前 | 顶层/电源页标题栏及旧报告 | schematic annotations / historical docs | 旧15..55V、15A/25A等叙述仍混在当前工程中 | 新图第1页注释仍为48V nominal;15..55V full-function，第2页仍15..55V design window；旧封装报告仍写15A连续/25A短峰值。当前授权24..48V/10A。 | 布局和后续修复可能按过时包络选件或以55V作为允许值；这不代表连接图本身已改变。 | 后续单独修订当前有效注释和文档基线；历史记录保留但加明确被替代说明，禁止把历史证据改写成新执行结果。 | 设计输入只有一套现行规格；计算示例越界电压与允许工作电压明确区分。 | OPEN
S17 | P2 | 已确认辅助工具误报 | 审计工具修复；不阻塞电气layout | board_parity_audit.py / F1/J6 | static audit | 辅助静态审计未识别off-board属性 | static_parity exit2仅将外置F1/J6列为缺板/缺封装；二者XML明确exclude_from_board且非DNP。原生板级网表157元件/166网、逐焊盘和原生parity通过。 | 误导后续修复者给外置保险和源端子添加板上占位封装。 | 为工具增加off-board识别及聚焦回归，仍保留真正板载缺失的检测；本报告人工解释，不改结果或忽略检查。 | 当前原始XML应不再误报F1/J6；删掉真正板载器件的mutation仍失败。 | OPEN
S18 | P2 | 已确认派生证据描述错误 | 审计工具修复；不阻塞电气layout | gate_ab_verify.py/qualification.json | derived evidence | corner_basis把INA REF1/REF2文字写反 | qualification.json文字为REF2=VA5;REF1=GND，实际新网表U2..4.7(REF1)=VA5、.3(REF2)=GND。对当前对称VA5/2公式数值无影响。 | 可能诱导后续错误改线；派生报告文字不能覆盖原生物理引脚证据。 | 后续修正描述并加入实际pin7/pin3对应回归；无需为使文字“正确”而交换原理图参考引脚。 | 新派生证据文字与物理网表一致，原有数值回归保持通过。 | OPEN
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

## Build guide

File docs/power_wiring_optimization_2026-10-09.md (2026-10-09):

# Power and ground presentation optimization

Based on the latest `origin/main`, commit `391dd90`, on topic branch
`fix/ocp-latch-industrial-review`. Existing untracked user files were preserved.

The native KiCad 10 hierarchy remains authoritative. The eight pages were
reviewed in full, with enlarged reviews of the interface power pins, regulators,
current amplifiers, ADC supplies, gate-driver supply, phase-U bootstrap/drain,
encoder receiver, clear filter, supervisors and buffer ports.

## Changes

- Removed seven isolated power-port/graphic pairs from the gate/inverter and
  current/ADC page headers; moved the ports onto visible circuit wiring.
- Moved all nine OCP hierarchy ports from the separate bottom legend to their
  actual circuit nodes. Added an explicit junction at the PWR_READY branch.
- Moved the AX7010 VIO power flag onto the connector supply wire.
- Added 54 native passive power/ground graphics at real local circuit nodes;
  retained the net-naming labels. These graphics are presentation symbols,
  not additional electrical power drivers.
- Made supply/ground labels horizontal, separated adjacent connector ground and
  VIO graphics, moved the C93 fields away from signal ports, and corrected
  page-edge text and the system sheet/title-block clearance.
- Added `tools/check_power_wiring.py` to both CI workflows. It deliberately
  ignores same-name label links and requires every power graphic, power flag
  and child hierarchy port to reach a real component pin by visible wiring.
  It detects the original isolated groups before the repair.

## Verification

KiCad XML exports were compared with the skill's exact connectivity comparator:
**159 system components / 180 nets / 648 pin memberships**, unchanged.
The PCB export independently contains **157 board components / 179 nets**;
external F1 and J6 remain outside PCB placement.

Final ERC: **0 errors / 0 warnings / 0 exclusions**. The inherited ignored-check
list is unchanged. No ERC severities or exclusions were modified.

The five repository source checks, new visible power-wiring check, native
netlist safety check, OCP digital behavior check (531 scenarios), and 11 PCB
checker regression tests passed. BOM regeneration produced no content changes.

PCB SHA-256 remains
`581f590151e439a771ab280e0449887680f917d3f7b9451c74a67d4b1b849eec`.
The PCB, footprints, physical pin assignments and XDC were not changed.

Review artifacts are under `artifacts/power_wiring_review/`: `before.xml`,
`final.xml`, `before_erc.json`, `final_erc.json`, `final.pdf`, `final_1.png`
through `final_8.png`, and `crop_*.png`. The machine-readable current visual
audit is `.pcba-workflow/schematic-visual-audit.json`.

This completes the schematic wiring/presentation repair. It does not close
the existing PCB synchronization/routing, footprint qualification, power-energy
or bench-timing gates in `docs/release_gates.md`; no PCB DRC was rerun because
the board bytes are unchanged.

## PR review evidence

[Final eight-page schematic PDF](reviews/power_wiring_2026-10-09/final.pdf),
[gate/inverter page](reviews/power_wiring_2026-10-09/gate_inverter.png), and
[OCP latch page](reviews/power_wiring_2026-10-09/ocp_latch.png) are included in Git.
The same directory contains the baseline/final XML netlists, ERC reports,
regression output and original failing power-wiring check for reproduction.

## Inherited CI blocker

Fresh PCB parity still fails on the unchanged board: extra board-mounted F1
and J3.1 on VIN_RAW instead of VIN_FUSED. PCB constraints pass. These are the
existing deferred synchronization findings in `docs/release_gates.md`; exact
schematic net equivalence and unchanged PCB bytes preserve this baseline.
The existing kicad-erc workflow runs PCB parity before ERC, so its job remains
expected to fail at that gate. Native ERC was run independently and is clean.
See [fresh parity report](reviews/power_wiring_2026-10-09/pcb_parity.json).

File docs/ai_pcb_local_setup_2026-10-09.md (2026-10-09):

# AI PCB 本地技能与验证环境 — 2026-10-09

后续更新：用户已确认 AX7010 2022 / J10，F1 已选择外置 KLKD025.T + LPSM0001Z；新增原理图优化后的板级网表为 157/179，PCB 暂不修改。下文 158/180 和 parity PASS 是部署当时的历史基线；当前结论见 [原理图优化记录](schematic_optimization_2022_j10_2026-10-09.md)。

## 安装结果

从用户提供的 `AI_PCB_fpga_servo_engineering_guide_V1.0.zip` 安装四个项目技能到 `.agents/skills/`：`kicad-audit`、`kicad-schematic`、`kicad-layout`、`kicad-release`。保留现有 `fpga-servo-kicad-repair`；根目录 AGENTS.md 与用户指示优先。技能下轮会话可被自动发现，也可显式指定名称。

教程辅助脚本、测试和评审模板位于 `tools/ai_pcb_guide/`，来源及原始/安装后 SHA256 见其中的 `source_manifest.json`。ZIP CRC 完整性检查通过。不覆盖根 AGENTS.md、全局 MCP 配置、教程 HTML/PDF 或 hardware/.history/。

实际可用工具：

- KiCad CLI：`D:/Software/KiCad/10.0/bin/kicad-cli.exe`，10.0.3。
- KiCad Python：`D:/Software/KiCad/10.0/bin/python.exe`，已验证 `import pcbnew` 与版本 10.0.3。
- 默认 `python`：3.13.9。本次所有检查在它上面通过；CI 固定 3.12，本次没有验证本地 3.12。`py` 启动器不可用。
- 现有 KiCad MCP 可读取本工程 Windows 路径，`get_pcb_statistics` 调用成功。当前工具集合包含分析、ERC/DRC、报告/渲染/制造导出及部分原理图编辑能力；不能把工具包提及的另一 MCP 的同步或自动布线能力视为已安装。同步可使用 KiCad GUI F8，编辑可使用经验证的原生 pcbnew。

Windows 受限命令工具当前出现 `helper_unknown_error: setup refresh had errors`；只读与项目内部署/验证通过受审查的沙箱外命令完成。这是执行环境问题，未修改沙箱设置，也未读取环境变量或 .env。

## 可重复执行

在仓库根目录 PowerShell 中执行：

```powershell
& .\tools\ai_pcb_guide\scripts\run_kicad_qa.ps1
```

可用 `-KiCadCli`、`-PythonExe`、`-ProjectRoot` 显式覆盖路径；默认 KiCad 路径已适配本机。入口运行原生 ERC、XML 与原生网表导出、教程静态审计、五项仓库检查、11 项 PCB 回归、安全连接、531 项 OCP 稳态场景、逐焊盘 PCB 一致性和机械/网络类约束，再运行全部严重级别的原生 DRC（含一致性检查与内存铺铜更新）。无 `--save-board`，不保存 PCB；不改严重级别或排除项。

报告位于 `artifacts/pcb-qa/`，每步退出码见 `step_exit_codes.json`。存在违规时整体应失败，不能当作部署失败忽略，也不能将辅助静态审计当作制造资格。导出失败时不使用历史网表继续证明通过。Bash 脚本仅是补充 ERC/DRC 入口，路径已调整，本机未执行验证。

四个技能的格式验证命令（Windows 需 UTF-8）：

```powershell
python -X utf8 C:/Users/GCB002/.codex/skills/.system/skill-creator/scripts/quick_validate.py .agents/skills/kicad-audit
```

对另外三个技能分别运行相同命令。四项均通过；这只验证技能格式，不能证明任何自动布线或制造能力。

## 工具包兼容性修复

真实工程端到端验证发现教程审计只能读取旧版顶层 `(net code "name")` 表。本工程 KiCad 10 使用焊盘/走线/区域内嵌 `(net "name")`，因此原脚本误报 PCB 0 网络。另有 XML 与 PCB 对层级名中的 `/` 和 `{slash}` 表示差异，导致 27 个网络误报缺失。

增加两个回归测试，分别先验证旧代码失败，再修正遍历与名称规范化。原两项测试保留，共四项通过。遍历尊重引号，避免将封装描述字符串当网络。实际静态审计现在无缺失位号、无空封装、无多余电气位号、无缺失网络名。

静态脚本计 194 个非空 PCB 网络名称；MCP 的 195 包括空网络。原理图的 180 网络不同于 PCB 的名称集合：板上仍保留旧铜网络。逐焊盘一致性与原生 DRC 才是同步的主证据，较大的 PCB 网络数不是修复完成的证据。

## 本轮继续修复的实际基线

分支 `fix/ocp-latch-industrial-review`；源提交 `fb23c912807207f4ac4d6655744e02e941d80c5e`。本轮未改电气设计文件，未切换分支、提交、推送或合并。

| 检查 | 最新结果 |
|---|---|
| 原生网表 | 158 元件 / 180 网络 |
| PCB | 158 电气 + 4 机械封装，20 段走线，0 过孔，5 区域定义 |
| ERC | 0 错误 / 0 警告 / 0 排除 |
| 逐焊盘及原生同步检查 | PASS；原生一致性问题 0 |
| 仓库五项检查、安全/OCP/PCB 约束 | PASS |
| 既有 PCB 回归 / 教程回归 | 11 / 4 项通过 |
| 原生 DRC | 271 违规（220 错误 / 51 警告），另有 466 项未连接 |

DRC 类型：113 clearance、88 solder_mask_bridge、43 isolated_copper、17 shorting_items、8 track_dangling、2 tracks_crossing。五项继承的忽略检查仍需发布前审查，没有新增忽略项。

教程的 124 元件、32 封装、102 缺失位号是旧基线，不能据此重新替换当前已修复的 U19、分流器或 BOM。Gate 1/2 的同步部分已有通过证据；封装生产资格、Gate 3/4 布线和 Gate 5 制造验收仍未关闭。

## 下一阶段

继续沿用 `docs/pcb_repair_progress_2026-10-09.md` 与 `docs/release_gates.md`，不得把本次环境部署当作全部硬件修复完成。

1. 明确实物 AX7010 板卡版本/接口位号与逐针验证、F1 外置还是板载及其实际型号。这两个输入已向用户请求，未假设答案。
2. 核定剩余器件制造尺寸、铜厚/电流温升与细间距焊盘间隙冲突规则；保持板框和机械特征。
3. 保存板级快照，逐一审计旧铜的真实起止焊盘，只以验证过的同网替代路径替换。按 DC-link/半桥、栅极/bootstrap、Kelvin、OCP、ADC/编码器顺序推进，保留新鲜 DRC 与两面视觉证据。不能仅删旧铜来降低错误数。
4. 未连接和阻塞 DRC 清零且所有释放门禁关闭后，才评审制造输出与样机验证。

本轮实际修复对象是 AI 审计工具的两处兼容性缺陷，并建立可重复的本地检查入口；完整 PCB 布线仍未完成。

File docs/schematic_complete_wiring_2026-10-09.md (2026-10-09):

# Gate Driver / Current Sense 页内完整连线

日期：2026-10-09。分支：`fix/ocp-latch-industrial-review`。图纸保持 A4 横向；PCB 未修改。

## 已应用的两页优化

`hardware/gate_inverter.kicad_sch` 重新排布为使能与三路 PWM 门控、FD6288、并列的三个半桥及电机输出。门控输出、六个输入下拉、bootstrap、栅极电阻、栅源电阻、分流电阻、供电和去耦均通过实际导线连接。

`hardware/current_adc.kicad_sch` 重新连通三路 INA241/RC、上下窗口比较器、阈值分压、开漏故障汇流、温度分压、ADS8588S 模式配置、参考/REGCAP 以及电源和地。

本轮验收不再只看 ERC：对两页分别检查 **42 / 33 个页内网络**，每个网络的全部元件引脚及其标签都位于同一个物理导线连通分量内。同名标签不参与这个物理连通检查。修改前的页面作为负对照，能检出地、门控、驱动、采样和电源等网络的多个导线孤岛；修改后为零。

## 验证

- 前后原生网表的物理引脚分组完全相同：157 板载元件、179 网络；系统 BOM 为 159 项。
- 所有器件属性值、器件 UUID、引脚 UUID 不变。
- 五项仓库检查、网表安全检查及 531 项 OCP 稳态场景全部通过。
- 当前工作工程原生 ERC：0 错误、0 警告、0 排除违规。
- BOM、PCB、符号库、工程规则、顶层及其余五张子图与本轮开始前逐字节一致。
- PCB SHA-256：`581f590151e439a771ab280e0449887680f917d3f7b9451c74a67d4b1b849eec`。

## Global label 候选版

按用户提出的跨页 global label 方案，已在 `artifacts/schematic_complete/candidate/` 形成隔离候选工程。35 个跨页名称逐一确认对应唯一的原有根网络；候选工程 179 个网络的物理引脚分组与修改前完全相同，原生 ERC 为 0 违规，两页物理导线检查同样通过。

正式迁移需要同步其他子图的跨页标签、顶层接口和原有“禁止 global label”的检查规则。自动审批拒绝了这项工程范围的迁移和检查规则修改。目前等待用户明确确认，候选版尚未应用；工作工程暂保留原有层级接口和所有检查规则，避免留下不能通过验收的中间状态。

## 本地可审阅文件

- 已应用的完整连线两页 PDF：`artifacts/schematic_complete/Gate_Driver_Current_Sense_wired.pdf`。
- Global label 候选两页 PDF：`artifacts/schematic_complete/Gate_Driver_Current_Sense_candidate.pdf`。
- 当前工程完整 PDF：`artifacts/schematic_complete/wired.pdf`。
- 快照、前后网表、ERC、物理导线检查脚本、负对照与验证清单：`artifacts/schematic_complete/`。

这次不涉及 PCB 同步、布局、布线或制造放行。电气动态和实物验证仍按 `docs/release_gates.md` 执行。

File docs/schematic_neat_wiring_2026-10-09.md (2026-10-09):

# Gate Driver / Current Sense readability refinement

2026-10-09, branch `fix/ocp-latch-industrial-review`.

Only the geometry of `hardware/gate_inverter.kicad_sch` and
`hardware/current_adc.kicad_sch` was changed in this iteration. The snapshot is
`artifacts/schematic_neat/before/`. Existing work on other sheets was preserved.

## Drawing changes

- Arrange the half bridges W/V/U from left to right to follow the FD6288 output
  grouping. The external phase names and connector physical pin mapping remain
  U/V/W as before.
- Rotate the four-terminal shunts beside their half-bridge paths, allowing the
  high-side source to low-side drain connection to run directly between the
  MOSFETs. Force and Kelvin pin numbers and electrical connections are unchanged.
- Group bootstrap parts above their associated bridges; align the gate resistors
  and move the upper gate-source bias resistors clear of the shunts.
- Move logic bypass capacitors away from PWM input labels. Retain the repeated
  three-channel arrangement and distinct hardware enable block.
- Keep current amplifiers and RC filters in three aligned rows. Move their
  bypass capacitors away from the differential input labels.
- Align ADC reference capacitors with their corresponding pins, with the supply
  bypass bank below them and explicit common ground wiring.
- Use the existing 1.27 mm connection grid, with additional space where the A4
  drawing permits. Fine-pitch IC fanouts retain the necessary closer spacing.

## Measured geometry

Measurements count drawn schematic wires, not PCB tracks. Proper crossings
exclude junctions and wire endpoint contacts.

| Page | Wire segments before / after | Drawn wire length before / after (mm) | Proper crossings before / after |
| --- | --- | --- | --- |
| Gate Driver | 332 / 316 | 4330.70 / 4267.20 | 77 / 59 |
| Current Sense | 351 / 333 | 3957.32 / 3905.25 | 53 / 51 |

The selected drawing balances total distance, crossings and readability; it is
not a proof of the global shortest drawing. Gate Driver degree-two corners
increase from 168 to 177 while crossings decrease; Current Sense corners decrease
from 117 to 113. A perimeter-rail alternative was rejected because it increased
total wire length substantially. Detailed measurements are saved in
`artifacts/schematic_neat/geometry_metrics.json`.

## Verification

- Native schematic, connection grid, A4 layout, connectivity and design checks:
  PASS.
- Fresh native netlist: 157 board components / 179 nets; system BOM: 159 entries.
- Physical-pin net partitions exactly match the pre-edit native netlist.
- Independent wire-only continuity check: Gate Driver 42 nets / Current Sense
  33 nets; all page-local pins on each net are physically connected without
  relying on labels to bridge disconnected islands.
- Component properties, component UUIDs, pin UUIDs and library identifiers are
  unchanged.
- Native KiCad ERC: 0 errors / 0 warnings / 0 exclusions. No severities or
  exclusions were changed.
- Safety connectivity: PASS. OCP digital behavior: 531 scenarios PASS.
- Other schematic pages are byte-identical to this iteration's snapshot.
- PCB unchanged; SHA256:
  `581f590151e439a771ab280e0449887680f917d3f7b9451c74a67d4b1b849eec`.

The existing hierarchical interfaces are retained. The previously prepared
project-wide global-label migration remains unapplied. This drawing refinement
does not change the outstanding manufacturing and bench gates.

## Review exports

- [Two-page optimized drawing](../artifacts/schematic_neat/Gate_Driver_Current_Sense_optimized.pdf)
- [Full native schematic PDF](../artifacts/schematic_neat/final.pdf)
- Native evidence: `artifacts/schematic_neat/final.net` and
  `artifacts/schematic_neat/final_erc.json`.

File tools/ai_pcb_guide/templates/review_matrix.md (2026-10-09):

# PCB Design Release Review Matrix

**Project / Version**: ______  **Commit**: ______  **KiCad Version**: ______

| Gate | Owner | Evidence path/SHA256 | State | Reviewer / Date | Blockers |
|---|---|---|---|---|---|
| G0 Requirements | | | NOT_STARTED | | |
| G1 ERC/netlist/BOM | | | NOT_STARTED | | |
| G2 MPN/Footprints | | | NOT_STARTED | | |
| G3 PCB schematic-parity | | | NOT_STARTED | | |
| G4 DRC/thermal/EMI | | | NOT_STARTED | | |
| G5 Gerber/drill/BOM/assembly | | | NOT_STARTED | | |
| G6 Bring-up/OCP/recovery | | | NOT_STARTED | | |

Allowed `State`: NOT_STARTED, IN_PROGRESS, PARTIAL, PASS, BLOCKED, WAIVED. For WAIVED include owner, risk analysis and approval ID; release blockers cannot be silently waived.

## Evidence Manifest (illustrative)

```json
{
  "commit": "40-character SHA",
  "tool": "kicad-cli",
  "version": "10.x actual value",
  "command": "pcb drc --schematic-parity --refill-zones ...",
  "file": "artifacts/pcb_drc.rpt",
  "sha256": "sha256 of file",
  "result": "FAIL",
  "violations": null,
  "unconnected": null,
  "reviewer": null
}
```

Do not replace `null` with made-up zeros. Always store original reports and identify the commit used to run them.

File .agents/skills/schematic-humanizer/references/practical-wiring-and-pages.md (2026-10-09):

# Practical wiring and page review

## Repeated stages

Use one phase/channel as a visual template, then repeat its relative geometry.
For a three-phase inverter, use equal-pitch U/V/W columns; for current sensing,
use equal-pitch amplifier/filter rows. Preserve the actual force/sense pin mapping.
Align corresponding MOSFETs, gate resistors, gate-source pulls, bootstrap parts,
and shunts. Align INA outputs, series resistors, filter capacitors and bypass parts.
Keep high-current flow, gate drive, Kelvin sense and logic readable as separate paths.

Choose the pitch from the widest rendered block, including references, values,
pin names and labels, plus a free routing corridor. Do not use a fixed pitch that
forces the last phase into the page border. In KiCad, connection anchors must
stay on the project's grid (50 mil = 1.27 mm in this project); text can use a
smaller positioning grid. Check actual transformed pin coordinates after rotation.

Connect bootstrap, gate-resistor/pull-down and local output-filter loops with
native wires. Match labels for distant driver outputs or cross-block ADC signals
when a direct wire would cross a symbol or require a large loop. Wire length is
not the deciding threshold: inspect traceability, crossings and whitespace.
Keep the phase ordering identical at driver, power stage, sensing and connector.

## Labels and connection proof

On parent sheet symbols, place net text outside the symbol: right-justified at
left-facing port stubs and left-justified at right-facing stubs. Keep horizontal
text readable; vertical labels need clearance from component fields. Label
anchors must remain on a proven wire or pin, rather than merely near it.

Before removing a same-name label, trace the native wire graph. Two nearby stub
ends can be connected only by their labels, even when the page looks continuous.
A nearby hierarchical label can also name another wire island. Proximity and a
shared name do not prove that removing one preserves connectivity. Either retain
both and separate their text, or visibly join proven same-net stubs and then
remove the redundant label. Do not bridge unrelated pins or crossings.

A useful counterexample is two GND stubs with a short visual gap. Removing one
label can create a sheet-local GND net. Detect it by exact named-net and physical
ref/pin comparison, restore the original graph, then add the intended visible
wire and compare again. ERC alone may miss a plausible split ground net.

For KiCad, export both snapshots using the same version:

```powershell
kicad-cli sch export netlist --format kicadxml --output before.xml root.kicad_sch
# Apply presentation edits to the authoritative source.
kicad-cli sch export netlist --format kicadxml --output after.xml root.kicad_sch
python scripts/compare_connectivity.py before.xml after.xml
```

Invoke the comparison script relative to this Skill folder or use its full path.
Require exact component identities, net names and physical pin memberships.
A mismatch blocks promotion: correct the edit and repeat the export, comparison,
ERC and render. Do not normalize away a newly split net or renamed net to pass.

## Full-page geometry

Reserve the actual lower-right drawing-sheet title-block rectangle. Checking
only a note's anchor is insufficient: its rendered width can reach that rectangle.
Shorten local prose, wrap it deliberately or move detailed rationale to a companion
document. Keep safety conditions and qualifications intact. After changing any
note, inspect its full text extent and nearby wires again.

Render every hierarchical page from the root, plus enlarged crops of connectors,
IC pin banks, gate/boot loops, divider/filter nodes, power-good and reset logic.
Compare page edges, local wire junctions and note extents at readable resolution.
Keep PCB bytes unchanged during a schematic presentation-only task.

## Page numbers and Git badges

First identify the interface reporting the issue. In KiCad 10 Project Manager,
a green check means a tracked file is unchanged; a red hollow circle means
uncommitted changes. Confirm with `git status --short`. These are Git badges,
not ERC, connectivity or manufacturing approval. Untracked files have a separate
status; committed files can still contain electrical errors.

For missing page numbers:

1. Open the project root schematic, then navigate children in the hierarchy.
2. Inspect the root `sheet_instances` page and each child's `instances/project/path`
   page. Enumerate actual children; check count, uniqueness and intended ordering.
3. Export the whole hierarchy to PDF with drawing-sheet border/title block enabled.
   Check both the PDF page count and each rendered title-block `Id: n/N`.
4. If the PDF and source are correct but the editor omits them, inspect the
   Appearance panel's Drawing Sheet visibility, hierarchy panel visibility,
   zoom and current root/context. Do not rewrite page instances on that evidence.
5. If source numbers are missing/duplicated, repair them in the hierarchy navigator
   (Edit page number) and repeat export. If printing omits the frame/title block,
   enable Plot drawing sheet in the plot dialog.

An explicit `02 / 08` inside each parent sheet box can provide navigation context;
keep it synchronized with stored instances and clear of port names. It supplements
the title-block page ID. Never claim an editor preference was fixed unless the
actual UI was inspected and verified.

Official references:
- KiCad 10 Project Manager Git integration: https://docs.kicad.org/10.0/en/kicad/kicad.html
- KiCad 10 hierarchy, appearance and plotting: https://docs.kicad.org/10.0/en/eeschema/eeschema.html
- TI TIDA-00913 schematic, used for visual grouping rather than copied values: https://www.ti.com/lit/pdf/TIDROJ7

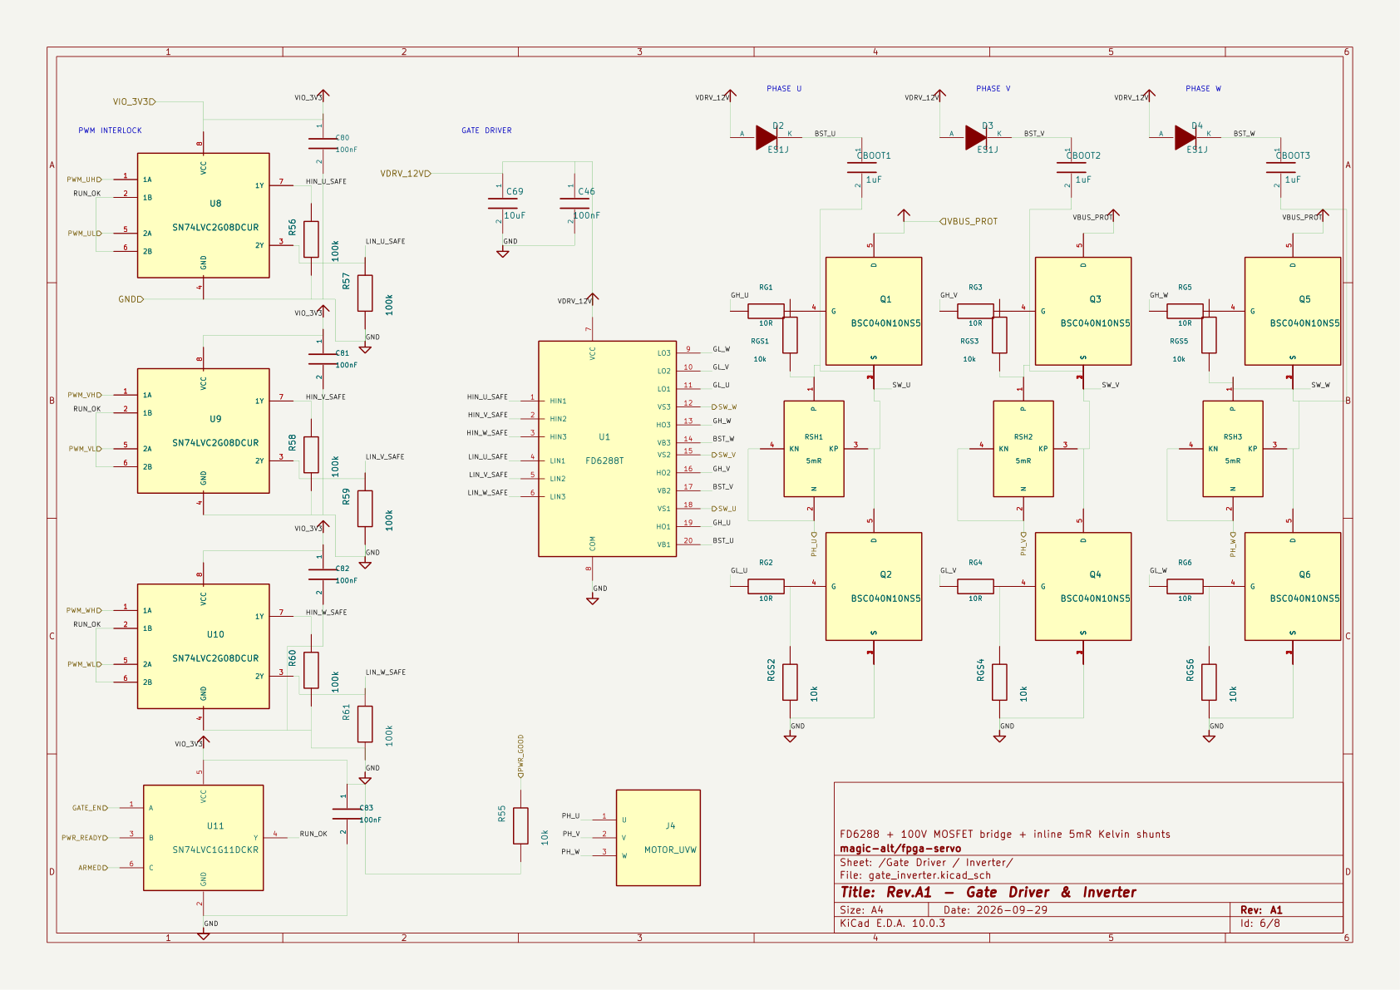
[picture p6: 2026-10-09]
docs/reviews/power_wiring_2026-10-09/gate_inverter.png

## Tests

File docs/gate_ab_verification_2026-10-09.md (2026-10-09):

# Gate A/B 电气审查与仿真资格化（2026-10-09）

> **结论：自动化证据已建立，但 Gate A = BLOCKED、Gate B = BLOCKED。**
> 本文档不是投板、功率上电、安规 STO 或保护响应认证。不得把脚本 PASS、GitHub CI 绿灯或纯被动 ngspice 结果解释为工程放行。

## 1. 设计基线 / 不确定性

- 源代码：`hardware/ax7010_servo_reva.kicad_sch` 和七张子页；目标 KiCad 10。
- 冻结的目标：24–48 V 母线、20 kHz PWM、10 A 连续相电流。当前计算暂按 **10 Arms**，实际额定定义、峰值电流、工作环境及散热、回馈能量/电源吸收能力均未获验收。
- 原历史证据（2026-10-09，非本轮新执行结果）：ERC 0/0、图板 parity PASS、PCB DRC 271 条违规 + 478 未连接。新的 CI 从每次提交的原生 KiCad 源文件重新导出；绝不通过复制历史 XML 来伪造本轮 PASS。
- `tools/gate_ab_verify.py` 对每份**新导出的 XML 网表**重核物理引脚、关键被动值、模拟/保护链路，生成容差计算和两份 ngspice 理想模型。原源及自定义物理焊盘、元件选型、PCB 此 PR 不修改。

## 2. Gate A：原理图电气冻结

| 领域 | 当前证据 | 状态 / 未完成条件 |
|---|---|---|
| 8 页原生电路/ERC | `kicad-cli sch erc --severity-all --exit-code-violations`；此 PR 的 CI 重新执行 | 自动检查可 PASS，但不替代器件应用审查 |
| 采样三相 shunt/INA/ADC | 对 RSH1..3 的 1=3、2=4 Kelvin 电气节点，INA241 REF1/REF2、C40..42、U15/U16、U6 实际脚序验证；人工仍审查 PCB Kelvin 路由 | 图连接回归可 PASS；采样精度/共模恢复未资格化 |
| ADS8588S 串行模式 | U6 16..22、27..33 接 GND；采样输入 49/51/53 及数据接口检查 | 连接检查可 PASS；ADC 采样时序/欠压仍开放 |
| Bootstrap | D2..D4 真实 pad1 阴极到 BST、pad2 阳极到 12V，CBOOT1..3 与 U1 实脚对应 | 静态拓扑可 PASS；充电电压、压降、刷新/最高占空比与 PCB 回路未验证 |
| 失电安全 | R80..R86 默认下拉、U24/U25 看门、U26/U23/U20/U11 门控由既有脚本及新回归覆盖 | **A-ADC-UNDERVOLTAGE：阻塞**；局部断电、未配置 FPGA、门极状态必须用真实电源/波形确认 |
| 器件/热/机械 | 曾检查 MPN、若干物理焊盘；详见 `docs/release_gates.md` | **A-VENDOR-FOOTPRINT-MPN / A-PEAK-THERMAL-SPEC：阻塞**；真实厂家封装图、最大负载、温度/散热需冻结 |

### A-ADC-UNDERVOLTAGE：确认的资格化缺口

根据 TI 的公开数据：ADS8588S 模拟供电 AVDD 下限 **4.75 V**；TPS3808G50 的标称下降阈值 **4.65 V**，按阈值 ±2% 的高侧也只有 **4.743 V**。

因此即使选择最早动作的阈值角点，也仍存在至少 **7 mV** 的 `AVDD < 4.75 V` 但监督器尚未确保触发的区间（而典型情况窗口可更大）。这不是“参考设计容差够小即可忽略”的问题；一旦 ADC 数据已失效而门控仍允许 PWM，保护无法把有效电流测量当作前提。Gate A **不能以 ERC=0 放行**。

处理选项（需要设计复核后实施，而非本 PR 盲改原理图）：使用能在 ADC 保证工作下限以上、计入检测器误差/迟滞/纹波的独立模拟许可或提高阈值的监督器；或定义与实现 **ADC 不可信时禁止 PWM 的硬件联锁**。验收需包含下降沿、上升沿、偏置电源分别丢失、复位与随机时序、全部角点。还需确认 G33 恢复的最坏约 3.194 V 与 AX7010 VIO 实际最低值是否匹配。

## 3. Gate B：动态功率及保护

| 模型/场景 | 此 PR 可重复计算 / 测试 | 不能从该结果推断的事项 |
|---|---|---|
| R50..53 OCP 阈值 | VA5=5 V 名义阈值高/低 4.70588/0.29412 V；约 ±22.0588 A；4.75..5.25 V、分压电阻 ±0.1%、shunt ±1% 被动角点扫描 | INA 增益/输出摆幅与失真、比较器失调及温漂、全速率过驱量、错误中断的总延迟 |
| R40/C40 | 理想一阶网络 τ=47ns，fc≈3.386 MHz；SPICE 验证门限越过时刻 | INA241 动态（公开 1.1 MHz 带宽/1µs 阶跃到 1%）、ADC 建立/抗混叠及开关共模恢复 |
| 直流母线回馈 | C1+C2=200 µF、理想无吸收 +1 A，从 48 V 到 55 V 仅 1.4 ms；能量差约 0.0721 J；ngspice 与闭式公式互检 | **55 V 并非允许电压**；未建模上游回充、ESR/ESL、感性浪涌、实际电容与制动器；无已合格吸收回路 |
| 栅极驱动 / 功率开关 | BSC040N10NS5 100 V VDS Max、72 nC Qg 上界（只在厂家给定测试条件），FD6288 标称 +1.5/−1.8 A 峰值、标称 200 ns deadtime | Qg/峰值电流除法只能作为**理想理论量级**，绝不是实际关断时间上界；未完成 vendor model + 半桥 SPICE、反向恢复、门极/开关尖峰、SOA 和热验证 |
| 总过流保护时延 | 现有纯数字 `check_ocp_behavior.py` 覆盖稳态 531 场景；前序 32 ns 仅限数字逻辑特定边沿、温度和负载条件 | 必须测 `t_INA+t_RC+t_comparator+t_logic+t_driver+t_gate_off` 全链路；TLV9024 100 ns 是典型值非最坏安全上界；还需故障脉冲、竞争、相位及不同上电顺序 |
| 开关电源 12V/5V | TI LM5164 额定 VIN 6..100V / 输出最高 1A；必须回到真实原理图及厂家计算工具/模型 | 负载阶跃、启动、磁件饱和、纹波、输出电压误差、辅助电源失效行为均未资格化 |

公式和波形均来自**当前源网表中的实际数值**（而非人工重复填写的历史器件值）。计算的角点为探索性假设，尚未证明 BOM 电阻温漂/电容额定值等满足所选容差。注意 10 Arms 下每个 5mΩ shunt 名义耗散 0.5 W，不等于 5 W 器件在该 PCB 上已热合格。

### 必须完成后才能关闭 Gate B 的实验

1. **真实器件模型及三相动态**：取得且确认版本/端口顺序的 FD6288、MOSFET（含门电荷/寄生二极管）、INA241、TLV9024、LM5164 模型，分别执行 24/48 V、极端 PWM/死区、故障正负电流斜率、不同 MOS 温度/栅阻及最大占空比；模型缺失不能写“仿真已完成”。
2. **实测保护总时延/波形**：受控低能量、具限流/隔离条件和合格差分探头测六路 VGS、各相 SW/母线尖峰、OCP_N 和实际门极消隐过程；覆盖开路/短路、短脉冲与 CLEAR 竞争。不能根据 32ns 数字逻辑加典型 100ns 比较器直接声称安全。
3. **回馈和源侧协调**：记录实际电源吸收能力、闭合回馈能量/OV 动作、外置熔断器 KLKD025.T 与 LPSM0001Z、输入线缆与真实故障电流/动作时间的协调证据。
4. **供电/采样时序**：真实 12V、5V、VIO 启停及任意部分供电组合，确认 ADC 无效时 PWM 确实禁止；三路电流增益、偏移、PWM 动态失真和 ADC 采样窗口。
5. **热/规格冻结**：确定 10A RMS 的系统含义、峰值/持续时间、最高环境及散热方式；测 MOSFET、shunt、端子、磁件在最坏运行点的稳定温度。

所有实测条件应写入 `docs/release_gates.md` 的原清单，并提供仪器截图、加载条件、签署人、硬件 PCB 版本、批次和可追溯 SHA。当前**无人执行实物台架，因此所有实测项仍开放**。

## 4. 可重复执行

工具已安装时，在仓库根目录执行统一入口（macOS/Linux/Windows，Python 3.12）：

```bash
python3.12 tools/run_gate_ab.py
# 同时收集 PCB DRC（当前未完成，应返回非零；不保存铺铜后的 PCB）
python3.12 tools/run_gate_ab.py --with-drc
# 工程门禁未关闭时，即使自动检查通过，也返回 2
python3.12 tools/run_gate_ab.py --strict-gates
```

可用 `--kicad-cli /完整路径/kicad-cli`、`--ngspice /完整路径/ngspice` 指定可执行文件。macOS 找不到 PATH 下的 KiCad 时，回退到官方应用内 CLI；不安装工具、不修改全局配置。默认使用启动入口的 Python 执行全部检查。

每次在 `artifacts/gate-ab/<UTC时间>-<随机标识>/` 创建独立目录。入口执行六项仓库检查、PCB/教程回归、原生 ERC、新 XML/原生网表导出、安全/OCP/PCB parity/约束、Gate A/B 计算、真实 ngspice 和网表 mutation 回归。`--with-drc` 增加全部严重级别、schematic parity 和内存铺铜 DRC；不使用 `--save-board`。

`manifest.json` 记录 Git SHA/工作区状态、源码与工具脚本前后 SHA256、工具版本、各步命令/退出码/日志、原生 ERC/DRC 计数、继承忽略规则以及产物哈希。源码变化使本次记录失败。原生报告结构缺失、导出失败、模拟器失败或超时都不能算 PASS；缺少新网表时不执行其依赖检查。每次目录独立，失败运行不会借用旧报告；保留日志供复核。

退出码：`0` 仅表示所请求自动检查通过；`1` 表示执行或检查失败（包括启用 DRC 后的违规/崩溃）；`2` 表示自动检查通过但 `--strict-gates` 要求的工程放行未满足。Gate A/B 仍为 BLOCKED。默认未执行 DRC 时明确记录 `NOT_RUN`，不能据此声称 PCB 合格。

低层 `gate_ab_verify.py` 仍可独立接收新 XML，但其 ERC 字段固定 `NOT_RUN`，已通过项只包含物理网表合同。**本次原生 ERC 结果以统一入口 manifest 为准**。低层仿真会删除本次预期波形文件后重新执行，检查波形有限值、单调时间和时间覆盖；失败会将输出 JSON 改写为 `FAILED`，防止旧 PASS 留存。

CI 使用同一入口，上传每次运行目录；当前 Gate A/B CI 不启用未完成的 PCB DRC。测试入口失败隔离：

```bash
python3.12 -m unittest discover -s tools -p test_run_gate_ab.py -v
```

## 5. 数据来源与模型边界

- [ADS8588S（TI）](https://www.ti.com/product/ADS8588S)：AVDD 4.75..5.25V、16bit、SPI/并口。
- [TPS3808（TI）](https://www.ti.com/product/TPS3808)：G50 标称 4.65V、G33 标称 3.07V；阈值偏差及恢复迟滞按器件版本复核。
- [INA241A（TI）](https://www.ti.com/product/INA241A)：A2 增益20，带宽 1.1MHz、动态恢复取决于 PWM 条件。
- [TLV9024（TI）](https://www.ti.com/product/TLV9024)：开漏输出、100ns **典型**传播延迟；不是保证最大关断时间。
- [FD6288（Fortior Tech）](https://fortiortech.com/en/product/hvic/hvic/fd6288)：3相半桥驱动、UVLO、内置死区/直通防止；必须取得 V1.6 原始手册检查完整时序及典型应用。
- [BSC040N10NS5（Infineon）](https://www.infineon.com/part/BSC040N10NS5)：100V 最大 VDS、Qg 58nC 典型/72nC 在特定条件的最大值，不能替代开关仿真。
- [LM5164（TI）](https://www.ti.com/product/LM5164)：6..100V 1A buck；磁件和板上负载须单独定量验算。
- 本仓库：`docs/ocp_latch_review_2026-10-09.md`、`docs/schematic_layout_entry_review_2026-10-09.md`、`docs/analog_safety_layout_review_2026-10-09.md`、`docs/release_gates.md`。

**记录规则：**“自动物理连线 PASS”、“被动/理想源仿真 PASS”、“器件模型 PASS”、“实物资格 PASS”分别记录，绝不能互相替代。

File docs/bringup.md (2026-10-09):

# Rev.A bring-up sequence

Current operating target: **24-48V, 10A continuous phase current, 20kHz PWM** (2026-10-09). Lower voltages below are diagnostic conditions only. The [layout-entry repair](layout_entry_repair_2026-10-09.md) closes diode polarity and ADC serial straps, but PCB routing/DRC and other release gates remain open before assembly/energization. No stage below is recorded as completed bench evidence.

## Stage 0 - unpowered inspection

1. Verify polarity/orientation of all MOSFETs, FD6288, regulators, ADC and current-sense amplifiers.
2. Verify no short between VBUS and GND, 12 V and GND, 5 V and GND, 3.3 V and GND.
3. Verify all six gate-source resistances match the intended pulldowns.
4. Verify shunt Kelvin pads are not shorted into the load-current copper except at the shunt terminals.

## Stage 1 - low-voltage auxiliary power only

Use a current-limited 15-24 V bench supply, <=200 mA initially.

Expected rails:

- 12 V rail in regulation
- 5 V rail in regulation
- VIO_3V3 is absent until AX7010 is connected; it is supplied by AX7010, not a local LDO
- once AX7010 VIO is present, `RUN_OK=0` while GATE_EN is high impedance or low
- all six gate-driver inputs low

Do not fit motor or high-current DC-link wiring yet.

## Stage 2 - FPGA I/O without bridge switching

Connect the active J1 2x20 interface to the confirmed AX7010 2022 J10; J2 is DNP. Verify physical continuity and orientation first.

1. Confirm all six PWM pins idle low after configuration/reset.
2. Confirm `GATE_EN` remains low by default.
3. Read ADC BUSY and perform conversions with static analog voltages.
4. Drive an RS-422 ABZ source and validate A/B/Z counting in PL.
5. Verify loss of AX7010 power does not source damaging current through the servo-board interface.

## Stage 3 - gate-drive verification

Power the DC bus at 15-24 V, current limited.

1. Fit bridge MOSFETs but no motor.
2. Enable one leg at a time with low duty.
3. Measure GH/GL directly gate-to-source.
4. Verify dead time, no simultaneous gate overlap and expected bootstrap refresh.
5. Measure switch-node ringing and tune gate resistors/snubber footprints if required.

## Stage 4 - current-sense verification

Inject known bidirectional current through each phase shunt independently.

Acceptance:

- zero-current output ~2.5 V
- gain ~100 mV/A
- monotonic from at least -20 A to +20 A equivalent input
- ADC code-to-current scale within calculated calibration tolerance

## Stage 5 - low-energy motor spin

Use 15-24 V bus and a small PMSM/BLDC motor.

- open-loop six-step or voltage-vector test first
- then current-loop FOC at low current
- verify current polarity and Clarke/Park phase order
- verify hardware OCP removes gate commands

## Stage 6 - 48 V qualification

Only after Stage 0-5 pass:

- increase to 48 V with current-limited source / suitable battery protection
- verify switching overshoot remains below device design margin
- perform thermal soak at 5 A then 10 A phase RMS under confirmed ambient/cooling; 15 A is no longer the continuous target
- perform regeneration tests with a safe bus-energy sink

## Configuration / OCP acceptance additions

- With AX7010 VIO present and the PL unconfigured, measure all six raw PWM inputs and GATE_EN low (10k pull-downs), then confirm all six FD6288 inputs remain low.
- Repeat with independent rail power-up, rail loss and AX7010 disconnect; capture gate-to-source voltages rather than relying on logic readings alone.
- Verify C43/C44/C45 connect VA_5V to GND, and C80..C85 are mounted at their associated IC supply pins.
- Test both polarities of all three OCP channels around the nominal +/-22.06A equivalent thresholds. Record tolerance and fault-to-gate-off delay.
- Confirm ARMED (TP5) and all six commands remain low after a fault recovers without a new FAULT_CLEAR edge. Test clear held high, clear during fault and clear with GATE_EN high. Re-arm only with EN low and healthy conditions; follow `ocp_latch_review_2026-10-09.md`, including recovery/removal phase scans and minimum-pulse tests.

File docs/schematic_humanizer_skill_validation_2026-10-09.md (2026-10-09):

# Schematic Humanizer reference validation

2026-10-09. This extends the installed upstream Skill with a reference rather than a second competing workflow.

A read-only subagent first answered three retrieval/application scenarios without the new reference: repeated inverter/sense stages; overlapping hierarchy labels/title-block notes; Git badges and missing page numbers. The baseline supplied reasonable generic guidance but lacked a concrete spacing recipe and could not identify the KiCad-specific badges or the source-instance/PDF diagnostic sequence. It explicitly reported those unknowns. It did not demonstrate unsafe editing.

After reading the Skill and new reference, the agent produced these actionable decisions:

- Choose phase/channel spacing from the widest rendered block plus a routing corridor; keep connection anchors on 1.27 mm and inspect transformed pins.
- Trace the native wire graph before deleting same-name labels; nearby stubs can be distinct wire islands. Require exact component identities, named nets and physical pin memberships after changes.
- Reserve the full rendered extent of notes rather than their anchors; separate source page instances, PDF page IDs and uninspected editor visibility.
- Identify the green check/red hollow circle specifically as KiCad 10 Project Manager Git status, independent of ERC.

The follow-up found no conflation of proximity with electrical equivalence, PDF success with a fixed GUI preference, or Git cleanliness with ERC success. This is a focused reference retrieval/application check, not a broad benchmark or independent full hardware-design approval.

Local application supplied a concrete counterexample: removing a visually redundant parent GND label split the exported net. The comparison failed (181 nets, added sheet-local GND); adding the explicit intended same-net wire restored exact 159-component / 180-net / 648-membership equivalence. The rejected intermediate drawing was not promoted. The final graph and unchanged PCB hash are recorded in `.pcba-workflow/schematic-presentation-proof.json`.

`python -X utf8 .../skill-creator/scripts/quick_validate.py .agents/skills/schematic-humanizer` passed. UTF-8 was required because the Windows default GBK decoder cannot read the upstream multilingual Markdown. The bundled comparison script ran against fresh before/final native XML exports and passed.

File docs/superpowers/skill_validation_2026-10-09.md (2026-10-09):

# Project KiCad skill validation

Baseline request: continue AX7010 OCP repair on a topic branch and determine layout readiness.
Without project skill, the independent agent selected the obsolete `.sch`, dual `.lib` and `check_legacy_schematic.py` commands from the old AGENTS.md. It correctly identified their possible conflict but could not inspect files because the default sandbox helper failed. This is a reference-discovery gap, not a claim that actual hardware tests failed.

Correction: native source paths, fresh netlist validation commands, physical package checks and separate ERC/layout/fabrication gates in the project skill; root AGENTS updated to native commands. Forward test and validator results are recorded after execution.

Forward test passed: independent agent selected the actual native top, verified the topic branch, ran the five checks successfully, identified stale release-gate counts and correctly withheld layout-freeze approval. `quick_validate.py` returned `Skill is valid!`. The stale release notes have now been refreshed. This is a project reference skill; no behavior-shaping wording micro-test was needed.

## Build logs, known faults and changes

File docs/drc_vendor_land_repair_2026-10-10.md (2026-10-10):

# Manufacturer land-pattern DRC repair - 2026-10-10

Development baseline only. DRC closure and fabrication release remain OPEN.

Online layout tools reviewed: [blwfish/kicad-mcp](https://github.com/blwfish/kicad-mcp), [Freerouting](https://github.com/freerouting/freerouting). The installed KiCad MCP reproduced the original 97 errors and the repaired 68 errors. Native KiCad 10.0.3 performed the controlled footprint migration and full parity checks. External routers were not installed or used to claim completed routing.

## Physical repair

U8/U9/U10/U20/U26 now use `fpga-servo:TI_DCU0008A_VSSOP8_P0.5mm`. TI DCU0008A drawing 4225266/A specifies example copper lands 0.85 x 0.30mm, 0.5mm pitch, row centers 3.1mm apart and R0.05mm corners. NSMD mask margin is +0.05mm; paste apertures match copper. The drawing's 0.125mm stencil thickness still requires assembly-process validation. Sources: [SN74LVC2G08 Rev.N](https://www.ti.com/lit/ds/symlink/sn74lvc2g08.pdf), [SN74LVC1G74 Rev.G](https://www.ti.com/lit/ds/symlink/sn74lvc1g74.pdf), [SN74LVC3G17 Rev.F](https://www.ti.com/lit/ds/symlink/sn74lvc3g17.pdf).

Previous generic copper lands were 1.25 x 0.35mm with row centers 2.8mm apart. Migration preserves board positions, rotations, pad UUIDs and nets. Only five schematic footprint properties and matching BOM entries changed. Before/after XML comparison passes for 164 components, 170 nets and 658 physical-pin memberships after explicitly accounting for the five footprint identity changes.

`tools/check_vendor_lands.py` failed on the old geometry and passes on the repaired board. `check_design.py` invokes this regression check. It checks copper dimensions and identities, not complete package procurement or assembly qualification.

## Verification

- Native DRC: **68 clearance errors /447 unconnected /0 parity issues**, previously97/447/0. MCP independently confirms68 errors and0 warnings. Its headline excludes unconnected items; native results remain the acceptance evidence.
- No clearance/severity settings or exclusions changed. Working project settings are byte-identical to the pre-repair snapshot, preserving the user's existing uncommitted changes.
- ERC: 0 errors /0 warnings /0 exclusions. All six project checks pass, plus vendor lands, fresh-netlist safety/OCP, PCB constraints/parity and 11 PCB regression tests.
- Schematic and board PDFs exported; eight schematic sheets and front-board view inspected. Schematic geometry unchanged.
- [Source hashes and counts](reviews/drc_vendor_lands_2026-10-10/summary.json), [raw DRC](reviews/drc_vendor_lands_2026-10-10/drc.json), [check results](reviews/drc_vendor_lands_2026-10-10/python_checks.json).

## Remaining work

The remaining 68 violations involve existing package pad spacing versus net-class rules, including ADC 0.20mm land gaps versus ANALOG0.25mm and power-connected package gaps versus POWER0.80mm. Moving the components cannot increase internal pad spacing. The pending engineering choice is to retain verified manufacturer lands with narrowly scoped same-instance pad clearance rules, or retain original spacing everywhere and select different devices/packages. Neither rule changes nor substitutions have been applied pending that choice.

447 connections still require routing. High-current copper, exact shunt/connector footprints and thermal evidence remain unfinished. S01 dynamic qualification, S09 sequencing and rapid VA5 droop/gate-off qualification remain OPEN. No brake circuit is added, following the latest user instruction. No release blockers are waived.

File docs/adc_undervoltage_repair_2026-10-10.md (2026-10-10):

# ADC 欠压硬件禁止与锁存修复记录

日期：2026-10-10。分支：`fix/adc-undervoltage-inhibit-20261010`；基线 HEAD：`58ddc5e29ff316f34002cf973014cde1fd32f42d`。本次根据用户批准落实审计 R1；报告中的验证对应提交前工作区。

**结论：原ADC欠压静态盲区已在原理图上消除，并同步PCB器件与物理焊盘网络；S01仍不能整体关闭。** 快速掉电到实际栅极关断的最坏时间、纹波、温度/寿命和供电时序尚未实测。正式layout冻结及制造放行仍被其余审计项和现有PCB违规阻塞。

原始[21项审计报告](schematic_layout_entry_audit_2026-10-10.md)及[清单](schematic_layout_entry_audit_2026-10-10_findings.csv)作为修复前历史证据保留。本记录补充当前状态，不把历史ERC/DRC计数当作新结果。

## 修改范围

原TPS3808G50监控门限可能低于ADS8588S的4.75V最低工作电压；仅调高监控门限又会与原固定5V稳压器的最坏输出重叠。因此同时修改5V稳压和独立监控，不依赖FPGA或ADC软件判断。

| 位号 | 新器件/设定 | 作用 |
| --- | --- | --- |
| U13 | TPS62901RPJR；外部分压；MODE=VIN | VA_5V标称5.1V，强制PWM 2.5MHz，VOS接实际输出 |
| R94/R95 | 75k/10k | 0.6×(1+75/10)=5.1V |
| U25 | TPS389001DSER；VDD由VIO供电 | 独立监测VA5，欠压拉低共用POR_N |
| R92/R93 | 3.24k/1k | 1.15×(1+3.24)=4.876V标称下降门限 |
| C94 | 100nF | 恢复延迟约107ms标称；不延迟欠压断言 |

四只分压电阻均采用Susumu RG1608N，0603，±0.05%，±10ppm/°C：R92=`RG1608N-3241-W-T5`，R93=`RG1608N-102-W-T5`，R94=`RG1608N-753-W-T5`，R95=`RG1608N-103-W-T5`。厂商目录中的5ppm V档不覆盖全部阻值，故未使用该档。0.1%寿命漂移是本项目计算分配，仍需按实际温度、工作寿命、批次和装配确认，不能理解为任意使用条件下的保证。BOM已重新导出；禁止用普通1%电阻替代。

## 实际封装脚序及禁止链

U13 RPJ0009A：1 PG→PWR_GOOD；2 SW→L2.1；3 VOS→VA5；4 GND；5 EN→VDRV12；6 VIN→VDRV12；7 MODE→VDRV12；8 SS/TR按数据手册允许开路使用内部软启动；9 FB→R94.2/R95.1。

U25 DSE0006A：1 SENSE→R92.2/R93.1；2 GND；3 MR→VIO；4 VDD→VIO和C91；5 CT→C94；6开漏RESET→POR_N。不能复用旧TPS3808脚序。

欠压使POR_N为低，经U26施密特缓冲、U23健康条件与门，使U20异步CLR有效，ARMED清零；U11 RUN_OK变低后六路PWM被禁止。电源恢复只解除复位，不会自行设置ARMED；仍要求健康条件、GATE_EN低和新的FAULT_CLEAR上升沿。VIO失电及部分供电的模拟行为仍需独立验收。

新增两种项目本地封装按TI推荐焊盘图绘制：RPJ0009A图4224505/A，DSE0006A图4220552/B。DSE 1–3脚阻焊收缩0.05mm形成SMD焊盘，4–6脚扩展0.05mm形成NSMD。铜焊盘几何及脚号已独立复核；钢网、板厂阻焊能力和装配验证仍未放行。

## 静态最坏情况计算

使用TPS3890参考1.15V±1%、SENSE漏电±100nA、迟滞上限0.825%；TPS62901外部FB参考0.6V±0.9%、FB漏电±70nA。每只电阻独立使用±0.25%界限：初始0.05% + 100°C温差×10ppm/°C=0.1% + 漂移分配0.1%。穷举参考、电阻及漏电的所有边界组合。

| 参数 | 当前结果 |
| --- | --- |
| 下降触发门限 | 4.808519–4.943948V |
| 最高恢复门限 | 4.984736V |
| 稳压静态输出范围 | 5.026621–5.173923V |
| 最低触发点至ADC 4.75V下限 | 58.519mV |
| 计入假设10mV负纹波后的恢复余量 | 31.885mV |
| 计入假设10mV正纹波后至5.25V上限 | 66.077mV |

10mV是设计预算，**不是测量结果**，也不覆盖负载突变过冲。静态门限余量无法保证任意陡峭掉电过程中先关PWM再退出ADC工作区。TPS3890的18µs是特定过驱条件下典型值，数据手册未提供可直接采用的最坏上限；禁止据此关闭快速掉电验收项。

VA5仍是共用电源。INA241零电流中心改为约2.55V；比较器标称上下阈值改为0.3000/4.8000V，对5mΩ、20V/V为约±22.5A。校准、ADC输入余量和实际编码器5V容差必须按新电源范围复核。OCP误差、桥臂故障覆盖及热设计未因此关闭。

## 新鲜验收证据

证据目录：`artifacts/adc-uv-repair/20261010/`。原始快照、前后XML、原生网表、PDF及8页图、ERC/DRC、回归日志、器件原厂资料、PCB同步证明和`verification.json`均保留在本地。关键摘要另存于`docs/reviews/adc_uv_repair_2026-10-10/`。

| 检查 | 结果 |
| --- | --- |
| 六项项目检查，包括可见电源接线 | 全部通过 |
| 原生ERC | 0错误、0警告、0排除；4种原有忽略类别未变 |
| 板上网表/系统XML | 162器件169网络 /164对象170网络 |
| PCB | 166封装，物理引脚/网络/值/封装/DNP一致性通过 |
| ADC静态门限检查 | PASS_STATIC_ONLY；动态资格明确为false |
| 新增故障注入 | 5/5通过，缺少新鲜XML时失败；已接入CI和gate runner |
| OCP数字状态检查 | 531种稳定状态场景通过，不代表模拟时序验证 |
| PCB回归 | 11项通过 |
| Gate A/B回归 | 18项中16通过，2项SPICE依赖跳过 |
| Gate runner回归 | 2项中1通过，1项端到端工具依赖跳过 |
| 教程一致性回归 | 4项通过 |
| PCB原生DRC | 268项违规、485项未连接、0原理图一致性问题；未放行 |
| 源文件差异 | 非授权器件的每个物理引脚网名完全相同；原有项目设置完整保留 |
| 图面检查 | 8页PDF逐页查看，重点复核辅助电源和锁存页的供电、分压及GND可见导线 |

PCB仅同步本次U13/U25替换及R92–R95/C94新增。新增器件处于暂存位置，尚未布线；原20条走线、5个区域、板框和4个安装孔保持。原开发板基线上的短路、间距等违规继续保留为待修问题，没有用降低严重度或排除项消除。

独立复核未发现Critical电气问题；提出的阻焊定义、缺失XML时跳过测试、未检查供电上限三项均已修正。最后统一刷新资格报告，避免旧数值混入交付。本次未进行新稳压器/监督器的有效模拟模型仿真或实体板测试。

用户原有`.kicad_pro`设置改动不纳入本次提交。另将相同原理图/PCB与仓库HEAD版项目设置复制到隔离目录运行原生检查，结果同为ERC零违规、DRC268项违规/485项未连接/0一致性问题；证明上述计数不依赖未提交设置。

## 尚需关闭的验收条件

1. 在实际温度/负载/输入范围内测VA5纹波、启动和负载瞬态；验证C31有效容量、L2饱和/纹波、强制PWM下轻载和电源吸收能力。不能只看标称22µF。
2. 控制VA5下降斜率及注入快速掉电，记录VA5、RESET、ARMED、RUN_OK和实际六路栅极。要求实际关断在ADC退出有效工作区前完成；以最坏总延时与最快下降斜率验证58.519mV预算是否足够，不满足则增加保持时间或改保护架构。
3. 验证VIO、VA5和12V任意上/下电次序、半供电、慢斜坡、反复欠压、CLEAR与故障竞争、恢复不会自动重启。验证C94容差/漏电/温度下的最短恢复时间及CLEAR协议。
4. 按系统定义确认ADC零点校准、OCP误差、编码器供电范围、寿命漂移和采购料号；验证推荐焊盘、阻焊与钢网工艺。
5. 继续处理原审计其余问题，完成真实PCB布局布线、DRC零违规/零未连接及发布门禁。S01当前状态为“静态设计已修复，动态资格OPEN”；S09供电时序仍OPEN，其他项未整体关闭。

## 原厂依据

- [TI TPS62901，SLVSFS7A](https://www.ti.com/lit/ds/symlink/tps62901.pdf)：外部FB精度、MODE、SS/TR、反馈和RPJ封装。
- [TI TPS3890，SLVSD65A](https://www.ti.com/lit/ds/symlink/tps3890.pdf)：可调参考、精度、迟滞、漏电、复位延迟及DSE封装。
- [Susumu厂家目录，RG系列，印刷页17](https://www.susumu.co.jp/common/pdf/n_e_all.pdf)：N/W订货编码、阻值范围、温漂和可靠性试验条件。

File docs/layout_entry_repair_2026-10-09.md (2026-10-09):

# 布局入口电气修复记录（2026-10-09）

分支：`fix/layout-entry-electrical`，从`79dd6fc`创建，保留原有未提交文档、项目设置和未跟踪文件。指标继续为24–48V、连续10A、20kHz。**两项明确原理图缺陷和三项图板一致性问题已关闭；完整PCB布局/布线和制造放行未完成。**

## 已实施修复

| 对象 | 修复及验证 |
|---|---|
| D2/D3/D4 | 本地及嵌入DIODE符号统一为K1/A2。保持图面阳极接12V、阴极接BST的方向，实际pad1接本相BST、pad2接VDRV。实例引脚编号同步，不旋转图形掩盖编号冲突。 |
| D1 | 同步修复TVS为K1/A2，实际pad1接VBUS_PROT、pad2接GND。继续DNP，没有批准装上SMCJ54A作为保护或回馈吸收器。 |
| U6 | 删除pins16..22、27..32共13个NC标记，以50mil网格原生导线接右侧地总线，逐T分支加junction，并放局部GND符号。保留REGCAP、参考、电源和DOUT/状态链路。 |
| ADC符号 | 新增`ADS8588S_SERIAL`，这13脚按已选串行模式定义为输入，原通用符号保留；pin33原为输入。避免双向输出与电源输出型地标志的13项类型警告，未改ERC矩阵、严重度或排除。精确模式接线规则确保不能把该专用符号当并行模式使用。 |
| PCB | 通过KiCad原生pcbnew对象更新22个焊盘归属（D1..4八个、U6十三个、J3.1一个），移除已改为板外的F1封装；J1复制隐藏的Board_Revision/Board_Connector字段。 |

物理极性依据[官方D_SMA](https://raw.githubusercontent.com/KiCad/kicad-footprints/master/Diode_SMD.pretty/D_SMA.kicad_mod)与[官方D_SMC](https://raw.githubusercontent.com/KiCad/kicad-footprints/master/Diode_SMD.pretty/D_SMC.kicad_mod)的阴极pad1定义；串行模式依据[TI ADS8588S Rev.A §8.4.1.13/.14/.17，p37](https://www.ti.com/lit/ds/symlink/ads8588s.pdf)。保留原BOM元件与MPN，不借本次接线修复声称器件完整资格已关闭。

Windows桌面自动化内核启动失败（helper ACL错误），可用MCP没有F8同步能力。因此使用[限定原生pcbnew修复工具](../tools/repair_layout_entry_pcb.py)，先生成22焊盘差异预览，再应用，不手改PCB文本来制造一致性。工具固定目标网与封装标识，拒绝旧错误网表，重复预览零变更；原生DRC一致性检查独立复核为零。

## 验证结果与网络差异

| 检查 | 本轮最终结果 |
|---|---|
| 原生KiCad ERC | 0错误 / 0警告 / 0排除；继承忽略配置不变 |
| 六项源检查 | 全部PASS；含本地/嵌入符号K1/A2、串行符号类型和可见电源接线 |
| 网表安全 | PASS：157板级元件 / 166网；系统XML159对象 / 167网 |
| 精确图连接变更 | 仅21个物理引脚网络归属变化：D1..4八个、U6十三个；所有元件值/封装与物理引脚集合不变 |
| OCP数字回归 | 531场景PASS，稳定电平限制不变 |
| PCB检查回归 | 11项PASS |
| PCB焊盘parity及约束 | PASS：157元件 / 166网 / 161封装（含四机械孔） |
| 原生图板一致性 | **3→0** |
| 局部ngspice46 | 六被动/理想源模型及独立公式检查PASS；结果与修复前一致，仅网表哈希更新 |
| 最终PCB DRC | **271违规：220错误/51警告；478未连接；0原理图一致性问题**，退出码1，验收仍失败 |

新增回归先对旧网表/符号运行，准确检出极性和ADC缺陷；修复后通过。旧网表179网减少至166网，是13个浮空串行引脚网并入GND的预期变化，不能沿用旧计数。没有减少元件或删除必需连接以满足检查。

最终DRC分类与前一轮相同：2 tracks_crossing、17 shorting_items、113 clearance、88 solder_mask_bridge、8 track_dangling、43 isolated_copper。478未连接比466多12，反映新增接地要求与同步后的连接图；本轮未布这13脚到地平面的真实铜。不能通过NC、隐藏飞线或忽略未连接来把这个数降下去。

## 保留项与仍未完成的PCB工作

逐原生对象及文本比较确认：所有20条旧走线的UUID/几何/网络/宽度/层不变；五铜区完整定义不变；板框不变；H1..4整个封装不变。其余保留封装的UUID/位置/方向/库标识均不变；仅上述七个封装属性发生预期变化，额外F1移除。工作区原有`.kicad_pro`改动本轮未覆盖。

对旧铜实际端点审查发现多数不落在当前真实焊盘上，并带VBUS、PGND、SW_U等过时网络名；部分跨过其他相或分压器。不能只按旧网名自动改名，也不能只删除旧铜来降低DRC数。需要在批准的器件位置上逐段确定起止焊盘，建立正确替代连接后替换旧路径。当前板只有20线段、零过孔，478未连接代表完整布线工作仍待开展。

另外，POWER网络类0.8mm间距也作用于接这些网的IC局部焊盘；细间距封装存在0.15mm等固有间隙。未经板厂工艺与器件焊盘依据复核，不把间距降小或添加排除来清零。正式功率布局仍需确认实际叠层/铜厚、板厂最小线宽间距、10A RMS含义、环境与冷却；自举刷新、辅助电源负载、回馈吸收、封装热和OCP台架门禁继续开放。已向用户请求这些参数。

## 图纸与证据

- [八页修复后PDF](reviews/layout_entry_repair_2026-10-09/final.pdf)、[八页总览](reviews/layout_entry_repair_2026-10-09/all_pages.png)、[ADC接地页](reviews/layout_entry_repair_2026-10-09/page_5.png)、[二极管页](reviews/layout_entry_repair_2026-10-09/page_6.png)。已视觉核查，地总线未接到REGCAP或DOUT。
- [原生ERC](reviews/layout_entry_repair_2026-10-09/erc.json)、[原生DRC](reviews/layout_entry_repair_2026-10-09/drc_final.json)、[parity](reviews/layout_entry_repair_2026-10-09/pcb_parity.json)、[确切网络变更](reviews/layout_entry_repair_2026-10-09/intentional_graph_delta.json)、[PCB同步变更](reviews/layout_entry_repair_2026-10-09/pcb_sync_applied.json)。
- [PCB正面](reviews/layout_entry_repair_2026-10-09/pcb_front.svg)、[背面](reviews/layout_entry_repair_2026-10-09/pcb_back.svg)、[修复前PCB快照](reviews/layout_entry_repair_2026-10-09/before.kicad_pcb)、[对象保留校验](reviews/layout_entry_repair_2026-10-09/pcb_preservation.json)、[仿真结果](reviews/layout_entry_repair_2026-10-09/simulation/results.json)。

独立审查再次确认两项电气修复、地总线与图板parity正确，并核对旧铜/机械保留。制造放行清单继续以[release_gates.md](release_gates.md)为准；原[布局入口审查](schematic_layout_entry_review_2026-10-09.md)作为修复前发现及完整仿真边界记录保留。

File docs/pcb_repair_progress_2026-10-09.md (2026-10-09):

# Execution ledger — plan: docs/superpowers/plans/2026-10-09-pcb-repair.md

Baseline commit: fe9b115. Topic branch: fix/ocp-latch-industrial-review. hardware/.history/ preserved.

Ruling: work in the current checkout on the explicitly approved repair branch, with snapshots — the approved plan specifies this branch and preserves user work; a second worktree would move the deliverable away from the shared project.

Baseline: five repository checks PASS; KiCad Python 10.0.3 available. Snapshots and hash manifest: artifacts/pcb_repair_before/.

Pre-flight: B supplies exact package/pad definitions to C; C supplies actual nets to D; D placement constrains E routing. All freeze gates depend on full parity and fresh reports, not declining legacy violation counts.

A: complete — fresh ERC 0/0/0; fresh baseline DRC 358 violations / 129 unconnected / 396 schematic parity issues. Count differs from prior 357 due legacy report variation.
B: terminal/shunt geometry and exact MPNs implemented; AX7010 physical revision and F1 implementation remain open.
C: complete — 158 electrical footprints plus 4 mechanical; physical-pin parity PASS; native DRC schematic parity 0. Assembly exclusions and schematic fields synchronized. Eleven checker behavior regressions pass, including rejection of extra numbered pads, missing values, DNP mismatch and absent actual power/bootstrap netclass assignments.
D: preliminary placement updated; package courtyard overlaps eliminated in native DRC; exact native netclass assignments installed; four 8mm mounting-head copper reservations added (mechanical assumption pending physical review).
Ruling: retain all 20 unqualified legacy tracks and the original zone pending endpoint-qualified replacement — deleting them would manufacture a DRC reduction and hide unfinished routing. Cost: the active board still has known shorts and must not be fabricated.
Ruling: use new persistent board UUIDs for replacement footprints — the old PCB source had no persistent UUIDs; schematic UUIDs and native paths are preserved.

## Fresh evidence after placement refinement

Saved/refilled board, KiCad 10.0.3: **271 violations / 466 unconnected / 0 schematic parity issues**. Violations are 220 errors and 51 warnings; unconnected items are separately reported errors.

| DRC type | Count |
|---|---:|
| tracks_crossing | 2 |
| shorting_items | 17 |
| clearance | 113 |
| solder_mask_bridge | 88 |
| track_dangling | 8 |
| isolated_copper | 43 |

No courtyard overlap, silkscreen collision, text-height or footprint-library mismatch was reported in this run. This does not prove electrical placement quality. Some proposed class clearances conflict with native fine-pitch pads; resolve through documented electrical/manufacturing rules rather than blanket relaxation. The existing board design settings are unchanged from fe9b115. The DRC report lists five inherited/default ignored check types (missing_courtyard, track_not_centered_on_via, tuning_profile_track_geometries, footprint_filters_mismatch, footprint_type_mismatch); no new exclusions or severity reductions were introduced. Review these before release.

The old 32-footprint partial board's 129 unconnected items cannot be compared directly with the complete 162-footprint board's 466. Missing circuitry is now visible; routing is still unfinished. All 20 legacy track geometries were compared against the snapshot and preserved. Nearest-pad endpoint audit is diagnostic only, not connectivity proof.

Fresh validation: all five repository checks PASS; netlist safety PASS; OCP digital behavior PASS (531 stable-level scenarios, no transient/bench claim); ERC 0 errors / 0 warnings / 0 exclusions; physical parity and constraints PASS; 11 behavioral regressions PASS; git diff --check clean. CI now runs the new physical parity and constraints against its freshly exported netlist. CI is not a routing/fabrication certificate.

Evidence in ignored local artifacts:
- artifacts/pcb_repair_before/manifest.json and source snapshots
- artifacts/ax7010_servo_reva.net and ax7010_servo_reva_erc.json
- artifacts/pcb_parity.json and pcb_drc_repair_stage.json
- artifacts/pcb_legacy_track_audit.json
- artifacts/pcb_repair_review.svg and .png (front copper/silkscreen visual review)

## Remaining dependent work

B is incomplete: actual AX7010 board revision and physical pin verification are required; F1 remains the schematic's unresolved external-fuse or onboard-25A choice. Both were requested from the user; no answer has been assumed. Manufacturer land-pattern verification for remaining critical ICs, MOSFETs and high-voltage capacitors remains open.

D remains preliminary: courtyard clearance is achieved, but proximity, loop areas, terminal access, mounting-head envelope and thermal arrangement need qualification with those actual packages/interfaces.

E remains unimplemented: replace legacy copper only with verified same-net endpoint routes; complete DC link/half bridges, gate/bootstrap, independent Kelvin pairs, safety/auxiliary and digital paths; refill and re-review both copper layers. Require DRC 0, unconnected 0, parity 0 and reviewed rules/exclusions before layout freeze. No complete-plan or freeze claim is made.

External protection/regen specifications, 2oz fabrication/current-temperature evidence, actual AX7010 VIO/partial-power behavior and OCP transient bench qualification stay open per docs/release_gates.md. Selected terminal/shunt ratings alone do not close them.

## Additional electrical correction from manufacturer review

TI INA241 datasheet SBOSA30D Table 5-1 explicitly requires reserved pin 4 to connect to ground. U2/U3/U4 had no-connect markers. Added a focused safety-netlist rule and first confirmed three failures on the old export, then grounded all three pins with short labeled wires. The local and embedded symbol pin types changed from no_connect to passive; the physical PCB pads now carry /GND. No control/interface pin or XDC assignment changed. Fresh netlist is **158 components / 180 nets**; three isolated NC nets disappeared. Three additional ground connections now require routing, giving the final **271 violations / 466 unconnected / 0 schematic parity**. ERC and all repository/safety/OCP/parity/constraint/regression checks pass after this correction. Exported current_adc sheet was rendered and visually reviewed.

Manufacturer basis: https://www.ti.com/lit/ds/symlink/ina241a.pdf (SBOSA30D, Table 5-1, page 2). The isolated NC nets disappearing is an electrical correction, not a routing improvement.

Independent read-only review: all three Important checker findings were reproduced and fixed; a second review confirmed the INA241 manufacturer requirement, minimal schematic diff, /GND on all three physical pad4 instances, 158/180 netlist count and fresh 271/466/0 DRC evidence. No remaining Critical/Important finding in the implemented stage. Full routing and release qualification remain unfinished. Changes are local on fix/ocp-latch-industrial-review; no push or merge.

## Superseding schematic-only change: AX7010 2022 / J10 and external F1

User confirms AX7010 2022 / J10 and requests schematic optimization with PCB layout deferred. Selected external KLKD025.T + LPSM0001Z; added external PSU wiring terminal J6; J3.1 is now VIN_FUSED. System BOM has 159 objects, current PCB netlist 157 components / 179 nets. Board file unchanged, physical parity deliberately pending (old F1 extra and J3.1 net mismatch). Prior parity 0 and DRC 271/466 above remain historical. Do not synchronize or route the PCB until that phase is requested. See `docs/schematic_optimization_2022_j10_2026-10-09.md` for current source verification and remaining qualifications.

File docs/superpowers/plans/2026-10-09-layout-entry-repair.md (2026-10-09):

# Layout entry electrical repair implementation plan

> **For agentic workers:** Use superpowers:executing-plans to implement this plan task-by-task.

**Goal:** Repair the two verified schematic defects, reconcile the PCB and report remaining layout work honestly on `fix/layout-entry-electrical`.

**Architecture:** Keep actual diode A/K direction while correcting physical numbers to K1/A2 in local and embedded symbols. Wire ADC serial-only inputs visibly to ground. Preserve mechanical features and existing work; validate intended graph deltas rather than claiming graph equivalence for deliberate repairs.

**Tech Stack:** KiCad10.0.3, native schematic forms, pcbnew, Python physical-pin checks, ngspice46.

**Spec:** `docs/schematic_layout_entry_review_2026-10-09.md`; 24–48V, 10A continuous, 20kHz.

## Global constraints

- No credentials/environment contents; no blanket exclusions or severity reductions.
- Preserve existing project settings, board outline and H1..4 centers.
- Never remove necessary copper solely to lower DRC counts or mark required pins NC.
- Incomplete routing and bench/thermal gates remain explicit.

## Review focus

- Symbol semantics vs actual K-marked footprint pads.
- ADC serial-mode pins and unaffected DOUT/control connections.
- New ground bus must not intersect REGCAP/reference or other signals.
- PCB sync must include off-board fuse removal, J3 net and J1 custom field without fabricating parity.
- Existing shorted/obsolete copper needs endpoint-qualified repair; prelayout unconnected count cannot be waived.

## Tasks

- [x] Create branch, inspect dirty state, save 12 hardware snapshots.
- [x] Add physical diode/ADC regressions; demonstrate failure on old netlist.
- [x] Correct local/embedded diode pin numbers, visibly ground13 ADC pins, regenerate BOM and netlists, ERC and six source checks.
- [x] Synchronize limited reviewed changes using native pcbnew (desktop UI unavailable), inspect exact pad/reference changes and preserve mechanics.
- [x] Classify DRC root causes, retain necessary paths, record478 unconnected and required fabrication/thermal inputs. Native parity issues corrected to zero.
- [x] Re-run local simulation, export/render modified pages, update status/release gates and complete independent review.
- [ ] Complete placement, endpoint-qualified replacement of legacy copper, full routing and DRC closure after fabrication/thermal constraints are confirmed. This is unfinished PCB work, not waived by successful electrical repair.

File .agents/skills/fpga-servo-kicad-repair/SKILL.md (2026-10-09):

---
name: fpga-servo-kicad-repair
description: Use when repairing the fpga-servo AX7010 KiCad hierarchy, OCP and power circuitry, ERC, schematic-to-PCB synchronization, or placement readiness in this repository.
---

# FPGA servo KiCad repair

Use the repository root containing `hardware/ax7010_servo_reva.kicad_pro`. Read root `AGENTS.md` and `docs/release_gates.md`. Keep changes on a topic branch, carrying existing uncommitted changes intact. Inspect `git status -sb` and save local snapshots before editing electrical sources. Do not push or merge merely because this skill is loaded.

## Find the actual design

The source is native KiCad 10: `hardware/ax7010_servo_reva.kicad_sch` with project-local `ax7010_servo_reva.kicad_sym` and `sym-lib-table`. The old `.sch`, `.lib` and `check_legacy_schematic.py` commands are obsolete. Enumerate sheet children from the top source instead of assuming a fixed page count. Count exported components and nets; zero ERC on an empty or stale export is not evidence.

On this Windows installation KiCad CLI and its pcbnew-capable Python are under `D:/Software/KiCad/10.0/bin`. If a tool cannot open the local Windows path, use local CLI/source checks instead of changing the project to satisfy that tool.

## Repair and verify the electrical graph

### Visible power and ground wiring

Apply the mandatory power/GND rules in root `AGENTS.md`. Put every supply,
ground and PWR_FLAG graphic at the circuit it serves, with a native visible
wire path to a real component pin. Child hierarchy ports must also reach real
pins by visible wires. An isolated port-to-power-symbol stub or label-only
legend is a failure even when ERC is zero and the named net is electrically
correct. Keep local decoupling, pulls and return paths readable; use labels
between distant functional blocks rather than long ground loops.

The project's `PWR_*` graphics are passive presentation symbols. Retain the
labels required to name their nets. When moving an endpoint, inspect every
intersected wire and pin; split new T branches and add explicit junctions.
Export baseline/final KiCad XML netlists and compare exact component identity,
net names and physical pin memberships with
`.agents/skills/schematic-humanizer/scripts/compare_connectivity.py`.
Run `python tools/check_power_wiring.py` and review every rendered page plus
power/ground crops. That check intentionally ignores label links; native ERC
and netlist equivalence remain separate acceptance gates.

Trace critical paths through exported physical pin numbers. Use manufacturer data sheets for package pin maps, power limits and timing. Compare library symbols, embedded definitions and footprint pad numbers; ERC alone cannot detect a plausible but wrong package mapping. Preserve all unaffected UUIDs, wires and sheet geometry during localized electrical repairs.

For hardware OCP, verify raw OCP diagnostic routing, asynchronous trip, supervised startup, default enable bias and deliberate re-arm. Fault recovery without a new clear edge must remain inhibited. Describe pulse-width and recovery/removal limits; boolean behavior checks are not analog transient or bench proof. Keep supply/regeneration energy and current/thermal assumptions visible when unknown.

After edits, export the BOM using `python tools/export_bom.py`, then export the netlist:

```sh
kicad-cli sch export netlist --output artifacts/ax7010_servo_reva.net hardware/ax7010_servo_reva.kicad_sch
python tools/check_native_schematic.py
python tools/check_kicad_grid.py
python tools/check_schematic_layout.py
python tools/check_schematic_connectivity.py
python tools/check_power_wiring.py
python tools/check_design.py
python tools/check_netlist_safety.py artifacts/ax7010_servo_reva.net
python tools/check_ocp_behavior.py artifacts/ax7010_servo_reva.net
kicad-cli sch erc --severity-all --exit-code-violations --format json --output artifacts/ax7010_servo_reva_erc.json hardware/ax7010_servo_reva.kicad_sch
```

Run any additional focused checks introduced by the change. Test a new safety constraint against the old faulty netlist before relying on its passing result. Review exported schematic pages visually after geometry or symbol edits. Update interface documentation/XDC together only if physical pin assignments change.

## Synchronization and release decisions

Before changing the PCB, compare schematic and board references, footprint IDs, pin counts and nets. Existing board footprints can be schematic placeholders; a successful sync dialog does not qualify them. Resolve missing footprints from vendor mechanical drawings and retain mechanical features. Save the board before synchronization, inspect the diff, and run fresh DRC after board changes. Keep unfinished routing and actual unconnected counts visible.

Report evidence in three parts: electrical changes; exact checks and fresh ERC/DRC counts; remaining release gates. Distinguish a schematic ready for provisional placement from frozen layout or fabrication release. Read `docs/release_gates.md` for outstanding OCP bench timing, surge/regeneration, connector and shunt ratings, AX7010 interface qualification and PCB closure. Never substitute ERC exclusions, deleted copper or invented footprint assignments for closure.

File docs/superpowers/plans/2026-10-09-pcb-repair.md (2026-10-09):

# PCB repair implementation plan — 2026-10-09

Goal: recover schematic/PCB parity, qualify real footprints, repair placement/routing and produce honest freeze evidence.

Constraints: existing topic branch; preserve hardware/.history; 130x95mm outline and H1..H4 fixed; connectors movable; 15A continuous/25A <=5s target; 5mOhm >=5W four-terminal shunts; external surge/regeneration protection mandatory; logic -40..85C; two layers/2oz target, fabricator qualification open.

- [x] A: baseline snapshots, fresh netlist/ERC/DRC and classified evidence.
- [ ] B: manufacturer-qualified terminals and shunts, local footprints, BOM and package evidence.
- [x] C: physical-pin parity checker; restore all electrical references and nets while retaining mechanics and audited copper.
- [ ] D: real-package placement, mechanical keepouts, actual netclass assignments.
- [ ] E: power/gate/Kelvin/safety/digital routing, zone refill, all-severity DRC and visual review.
- [ ] Acceptance: five repo checks, netlist safety, OCP behavior, ERC 0/0/0, physical parity clean, DRC 0/unconnected 0/exclusions 0; unresolved physical/bench gates stay open.

The approved conversation plan is the full behavioral specification. No pin assignment changes without matching interface/XDC updates. Do not delete copper to claim closure; replacement routes require matching endpoints. DNP parts retain pads. No guessed MPN or footprint qualification. Freeze depends on actual AX7010 revision, external protection specification, partial-power/OCP bench evidence and thermal qualification.

Execution status: A/C complete; B partial (terminal/shunt selections implemented; AX7010/F1 and remaining vendor qualification open); D preliminary; E and freeze acceptance incomplete. See `docs/pcb_repair_progress_2026-10-09.md`.

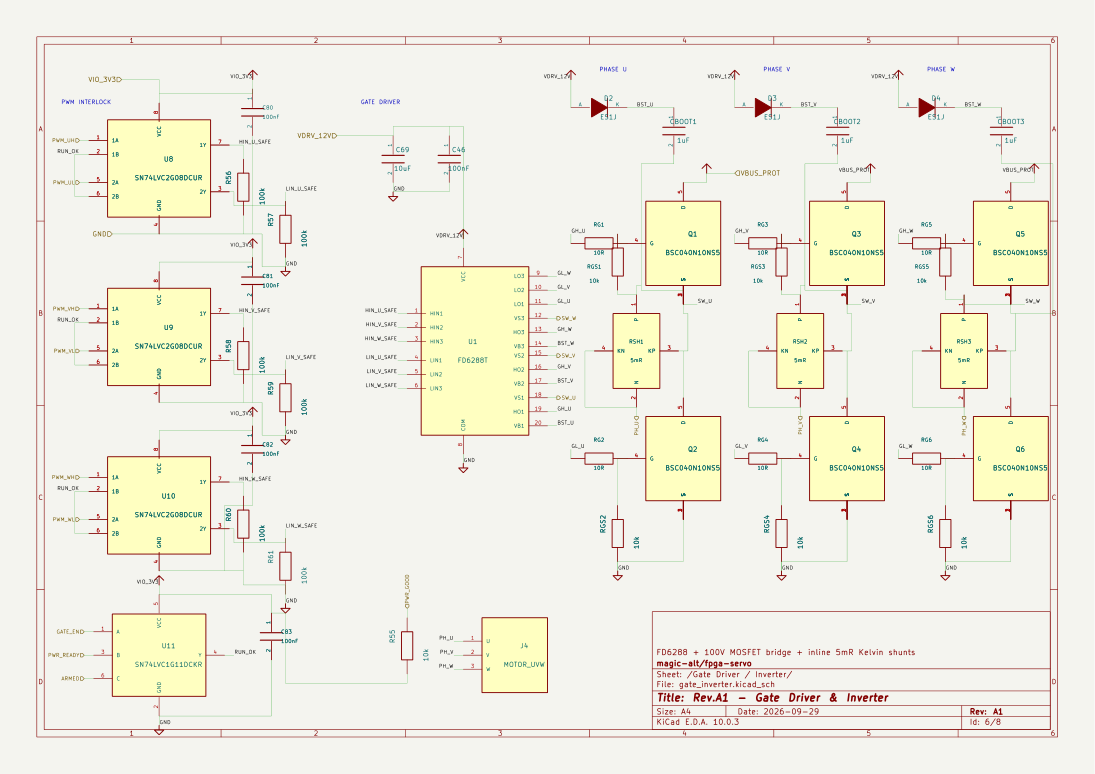
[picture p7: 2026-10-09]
docs/reviews/layout_entry_repair_2026-10-09/page_6.png

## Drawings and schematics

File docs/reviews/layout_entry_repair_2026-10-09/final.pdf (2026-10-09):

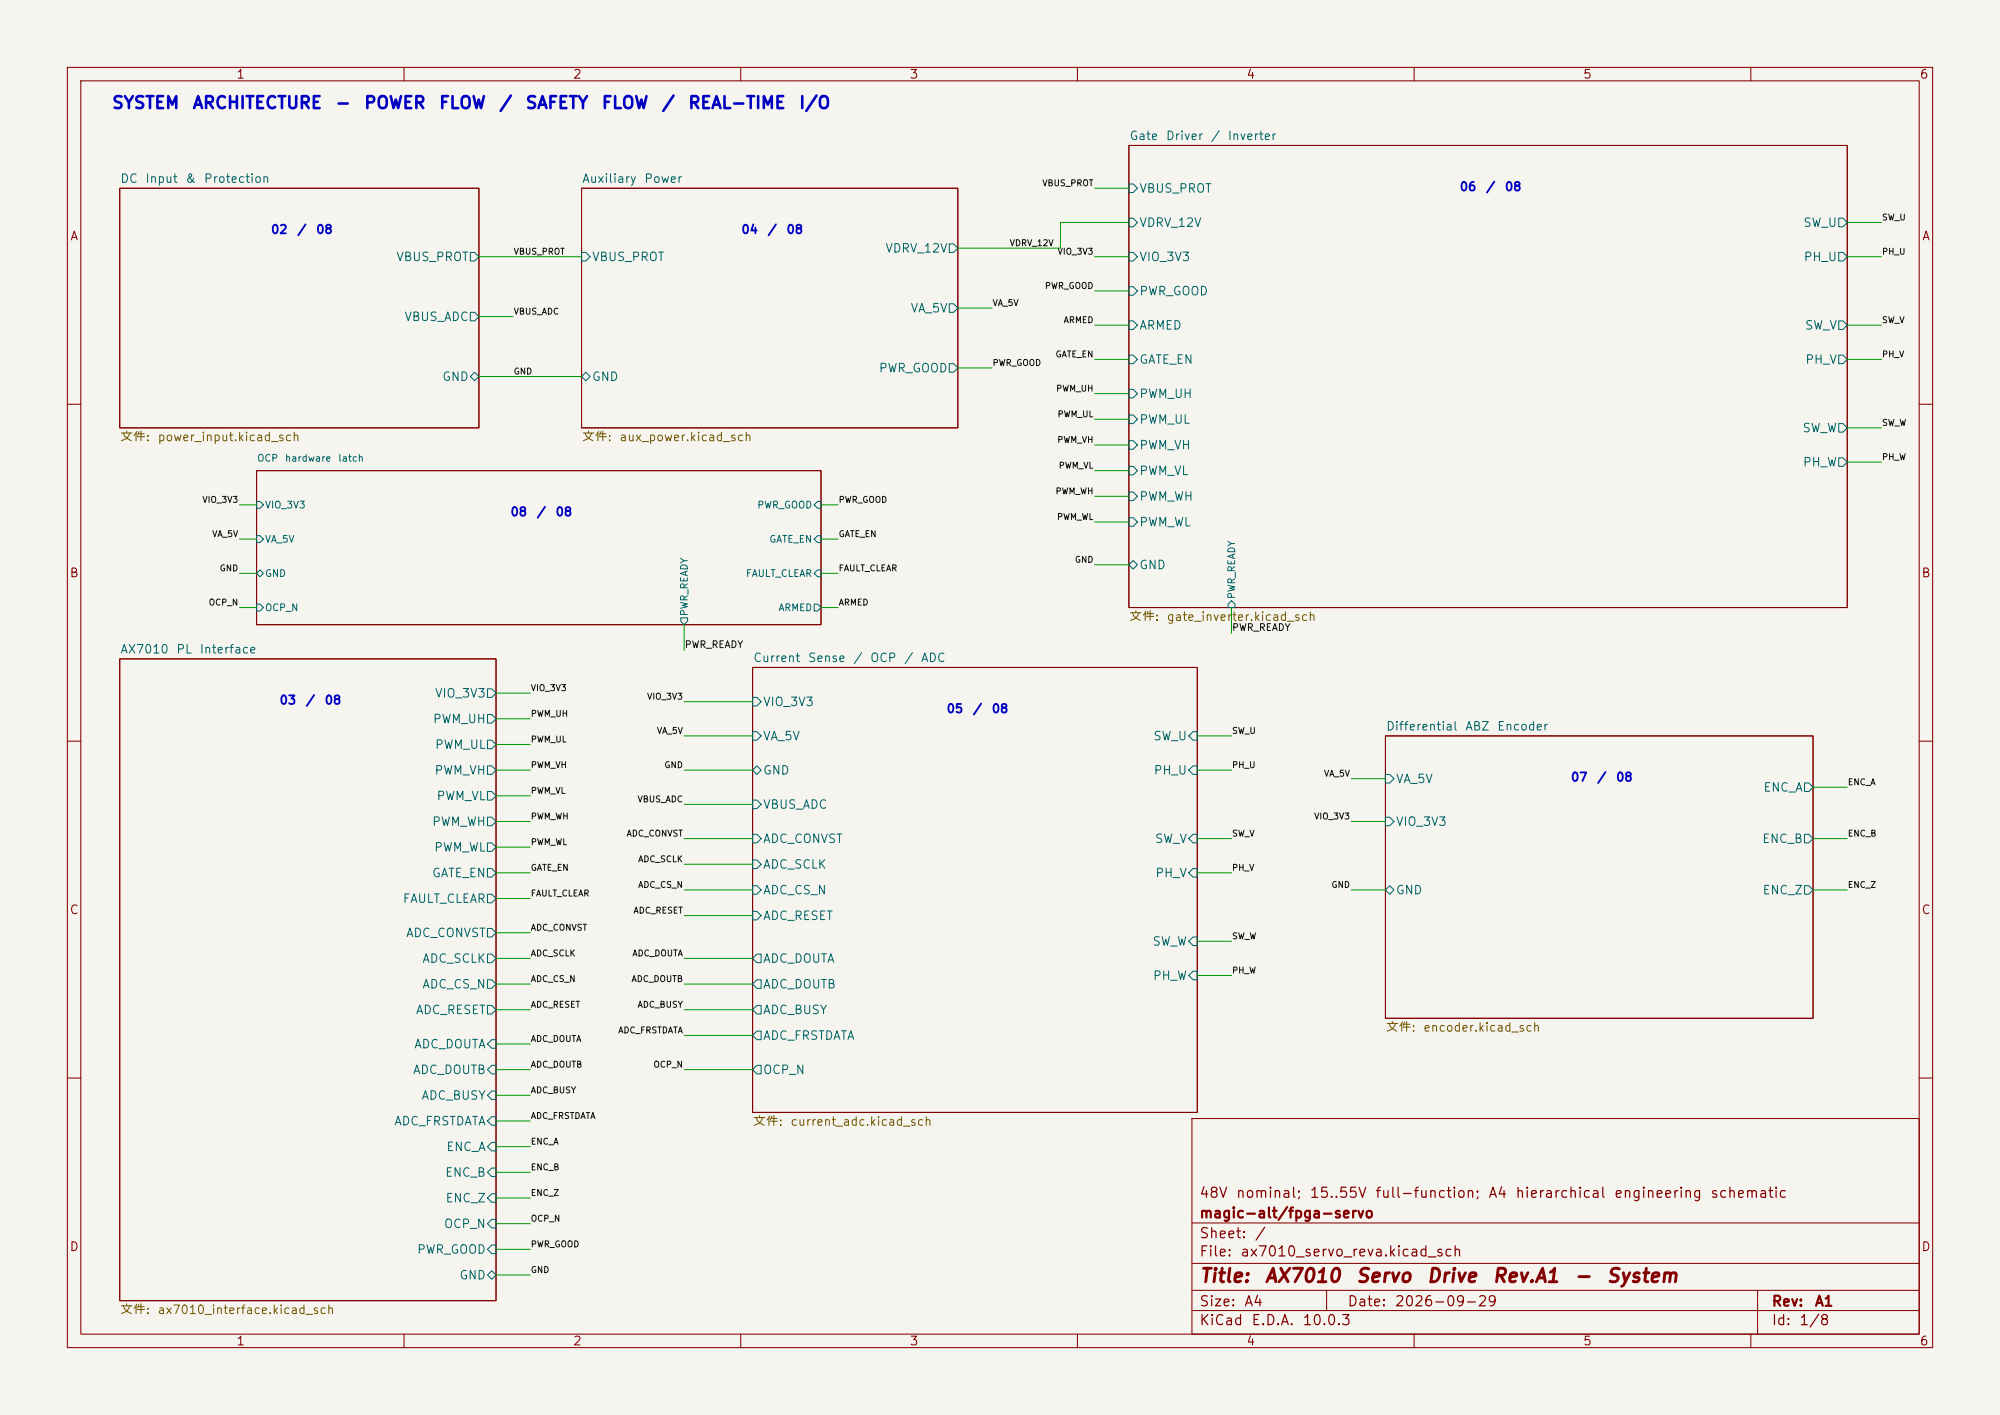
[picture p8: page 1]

PH_W PWR_READY Gate Driver / Inverter 文件: gate_inverter.kicad_sch
PWM_WL VDRV_12V PWR_GOOD

DC Input & Protection 文件: power_input.kicad_sch

ARMED
Current Sense / OCP / ADC 文件: current_adc.kicad_sch

ENC_Z Differential ABZ Encoder 文件: encoder.kicad_sch

48V nominal; 15..55V full-function; A4 hierarchical engineering schematic
magic-alt/fpga-servo
Sheet: /
File: ax7010_servo_reva.kicad_sch
Title: AX7010 Servo Drive Rev.A1 - System

Size: A4 | Rev: A1
KiCad E.D.A. 10.0.3 | Id: 1/8

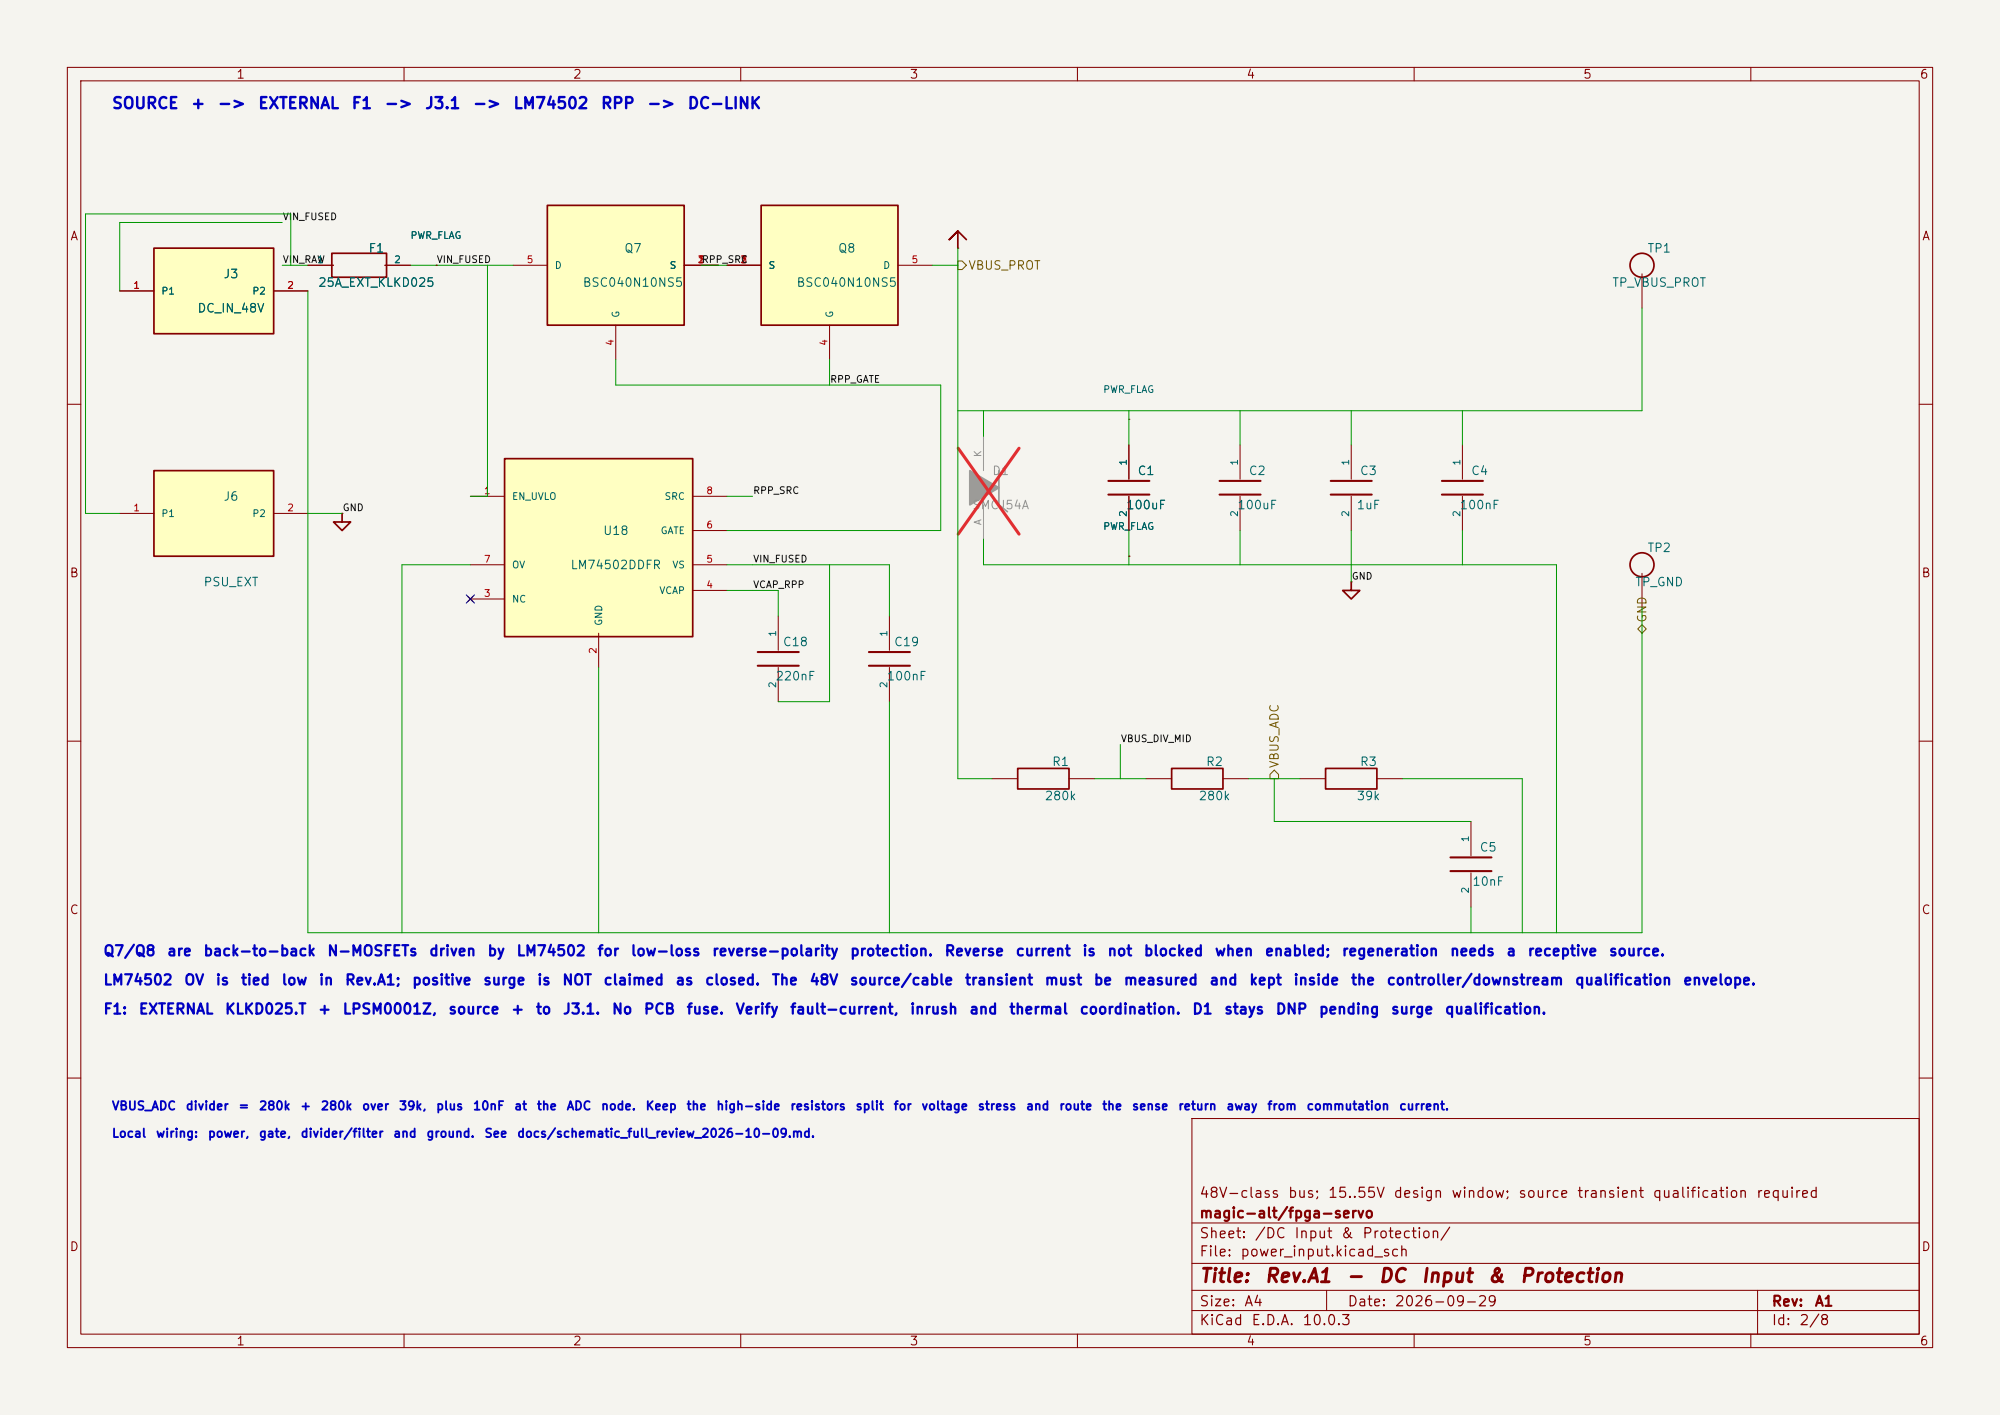
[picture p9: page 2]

SOURCE + -> EXTERNAL F1 -> J3.1 -> LM74502 RPP -> DC-LINK

48V-class bus; 15..55V design window; source transient qualification required
magic-alt/fpga-servo
Sheet: /DC Input & Protection/
File: power_input.kicad_sch
Title: Rev.A1 - DC Input & Protection

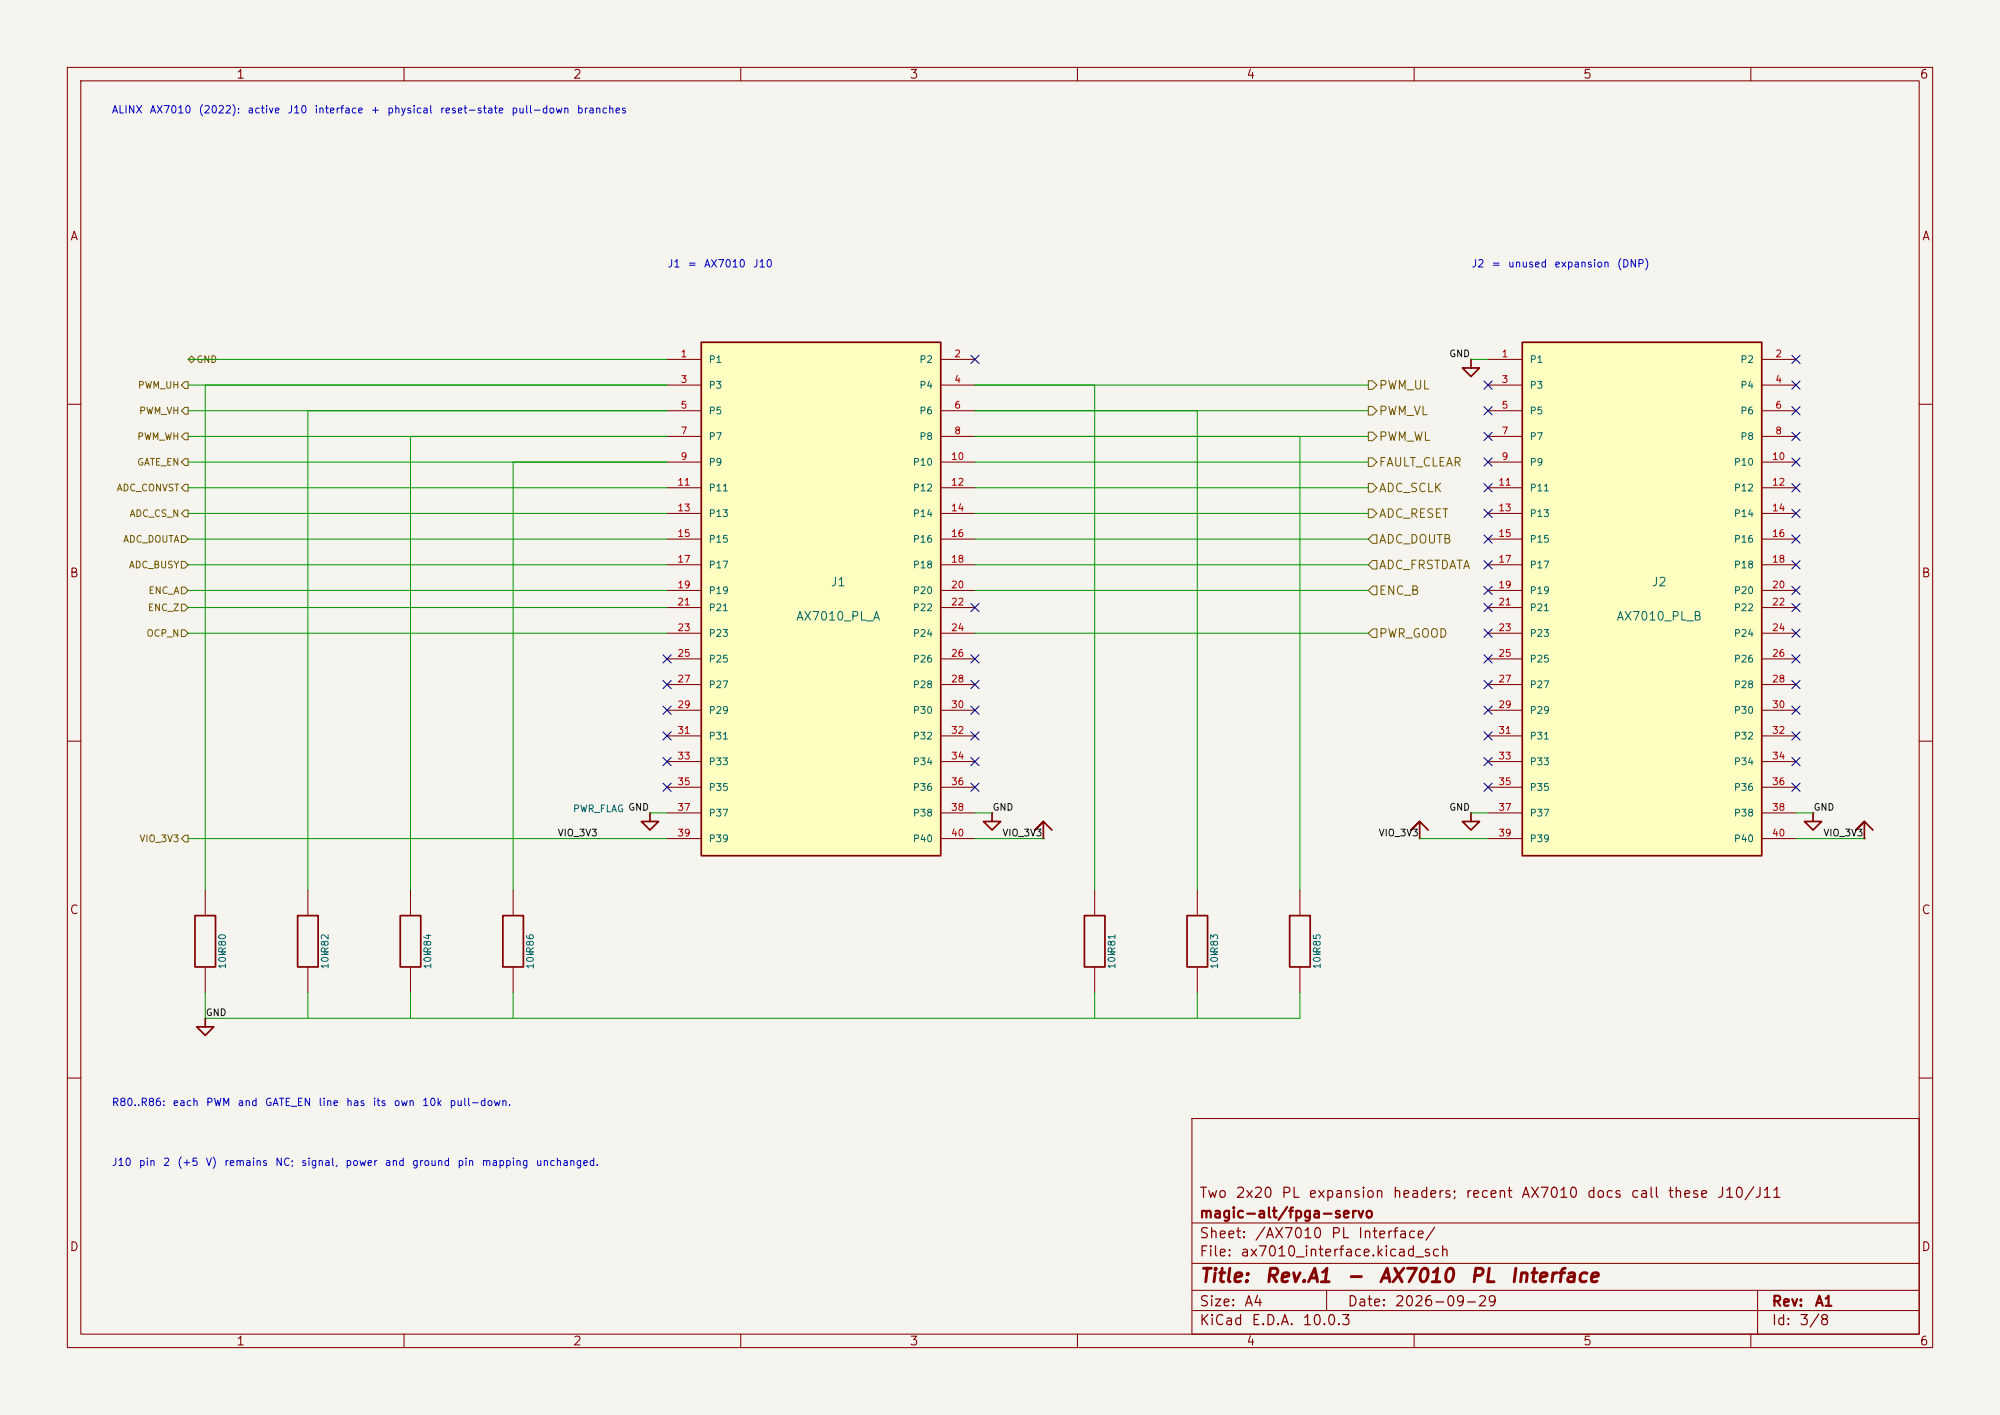
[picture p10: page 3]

ALINX AX7010 (2022): active J10 interface + physical reset-state pull-down branches

J10 pin 2 (+5 V) remains NC; signal, power and ground pin mapping unchanged. R80..R86: each PWM and GATE_EN line has its own 10k pull-down.

magic-alt/fpga-servo
Sheet: /AX7010 PL Interface/
File: ax7010_interface.kicad_sch
Title: Rev.A1 - AX7010 PL Interface

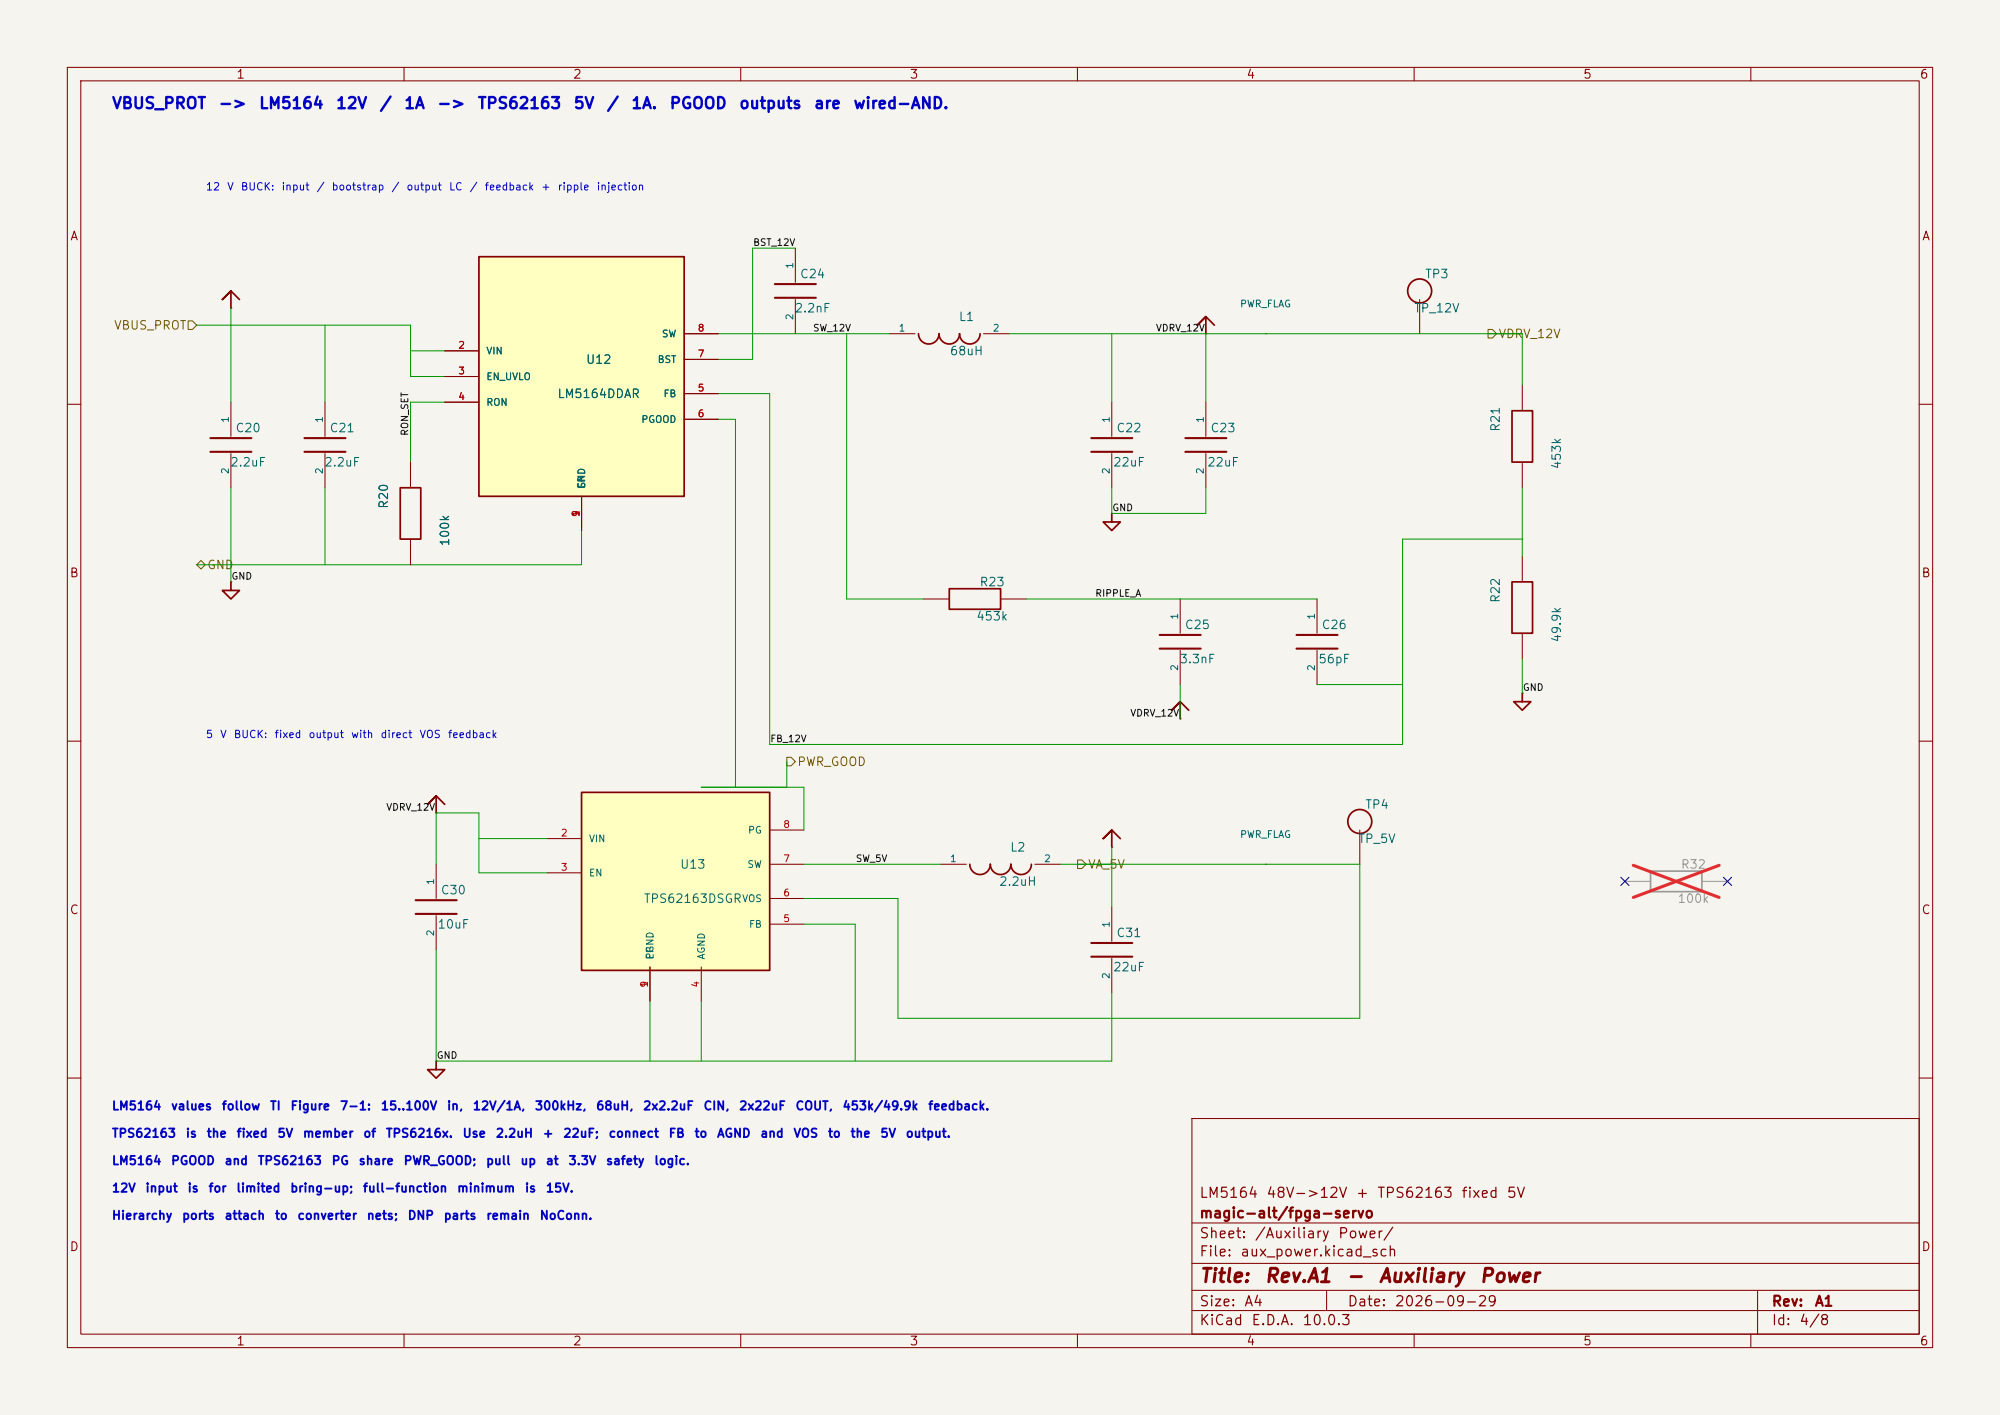
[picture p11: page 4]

12 V BUCK: input / bootstrap / output LC / feedback + ripple injection

LM5164 PGOOD and TPS62163 PG share PWR_GOOD; pull up at 3.3V safety logic.

magic-alt/fpga-servo
Sheet: /Auxiliary Power/
File: aux_power.kicad_sch
Title: Rev.A1 - Auxiliary Power

Hierarchy ports attach to converter nets; DNP parts remain NoConn.

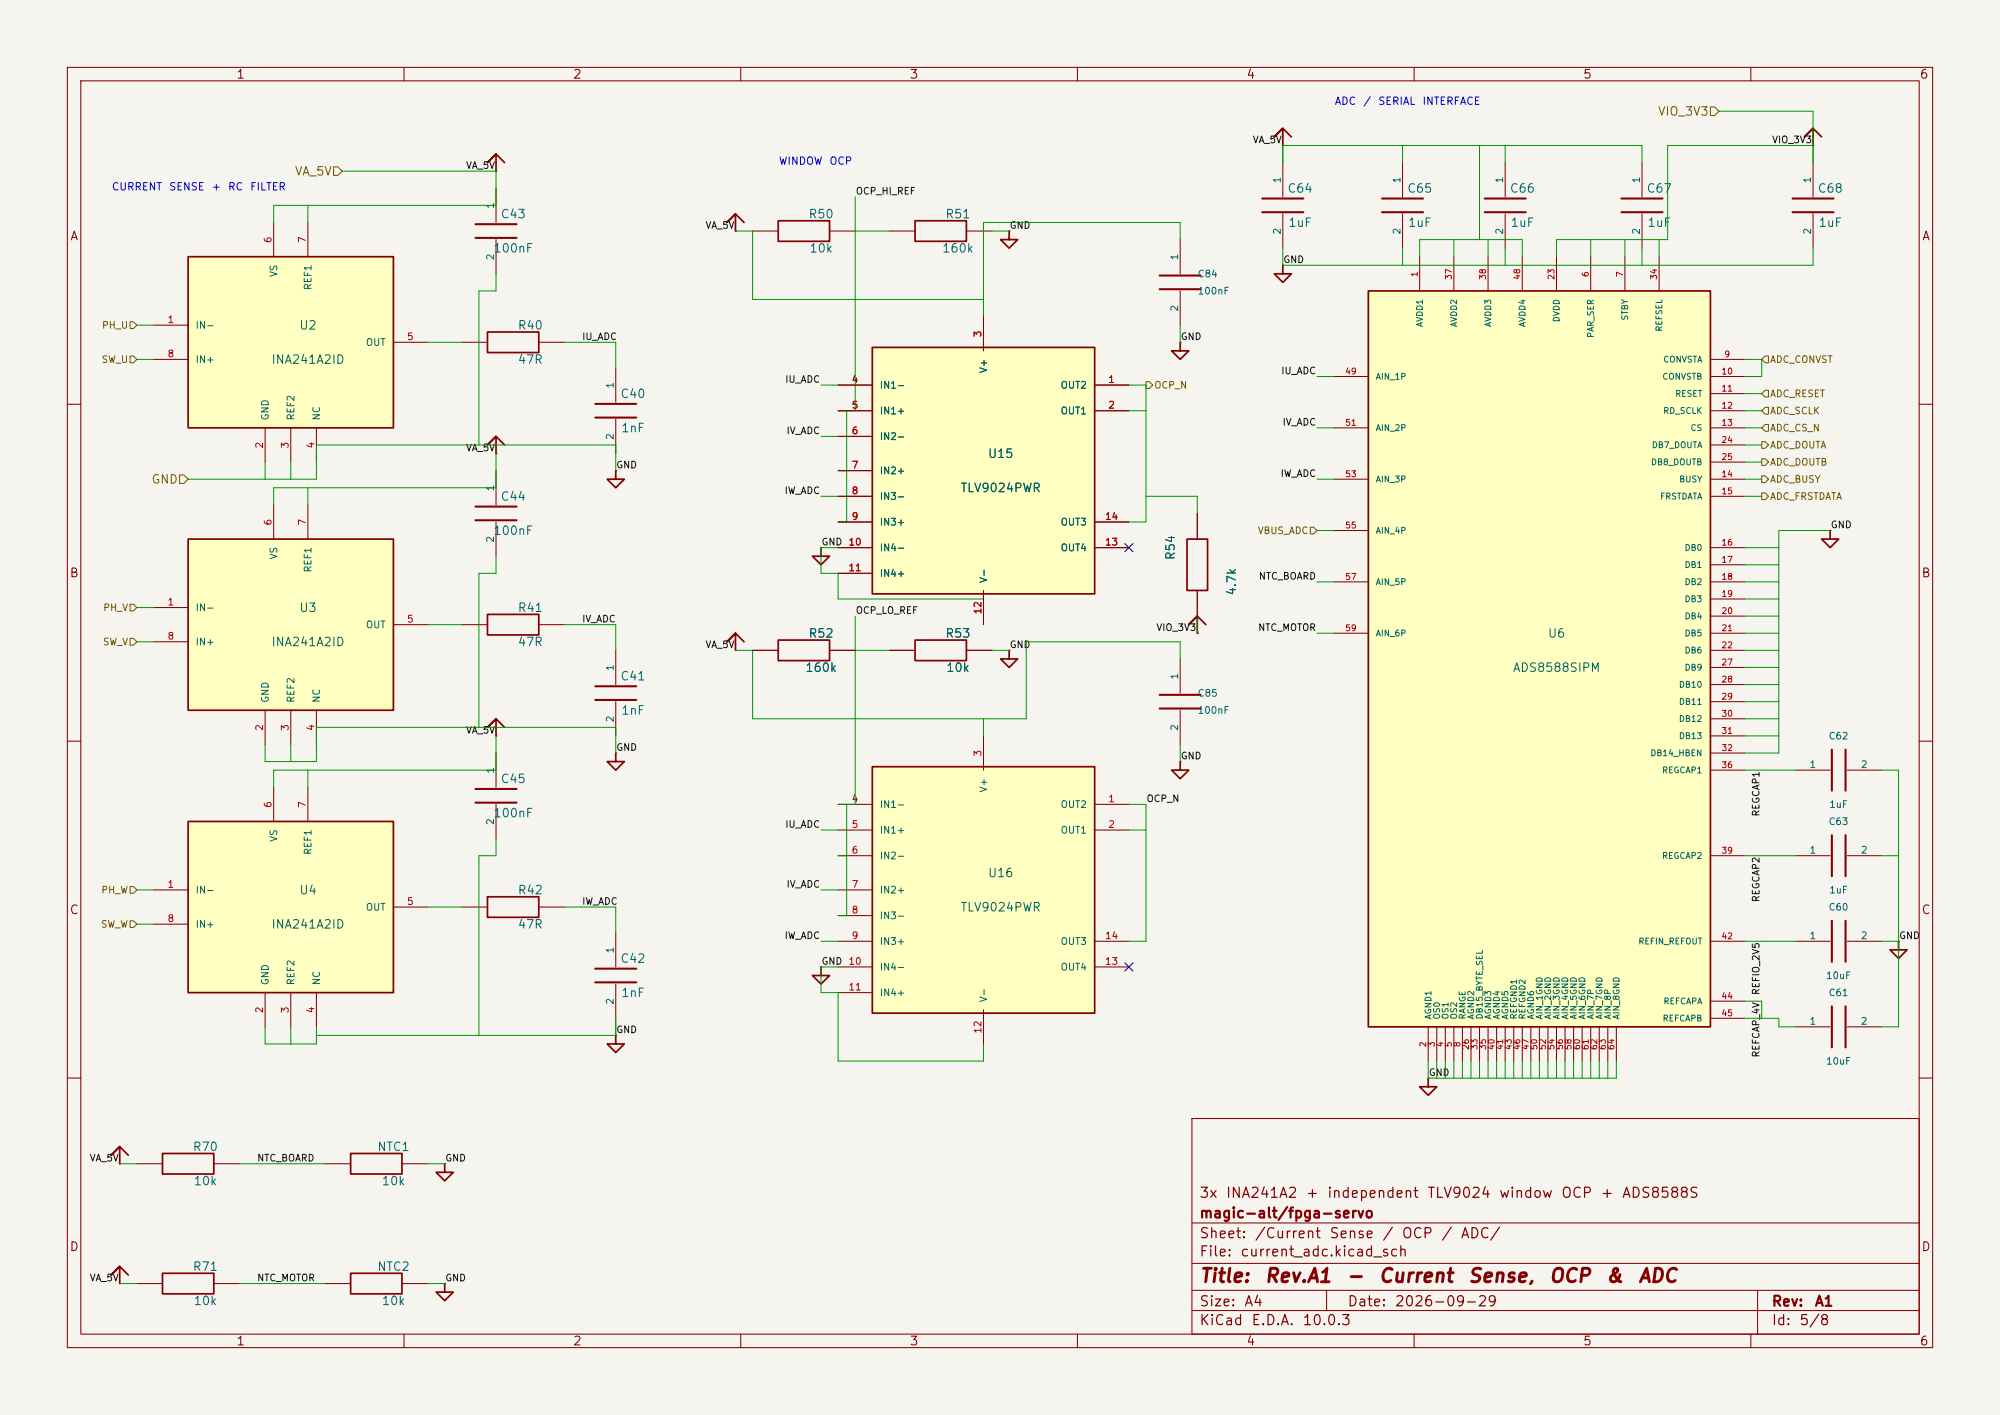
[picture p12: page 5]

6 STBY 7 RANGE 8 CONVSTA 9 CONVSTB 10 RESET 11 RD_SCLK 12 CS 13 BUSY 14

3x INA241A2 + independent TLV9024 window OCP + ADS8588S
magic-alt/fpga-servo
Sheet: /Current Sense / OCP / ADC/
File: current_adc.kicad_sch
Title: Rev.A1 - Current Sense, OCP & ADC

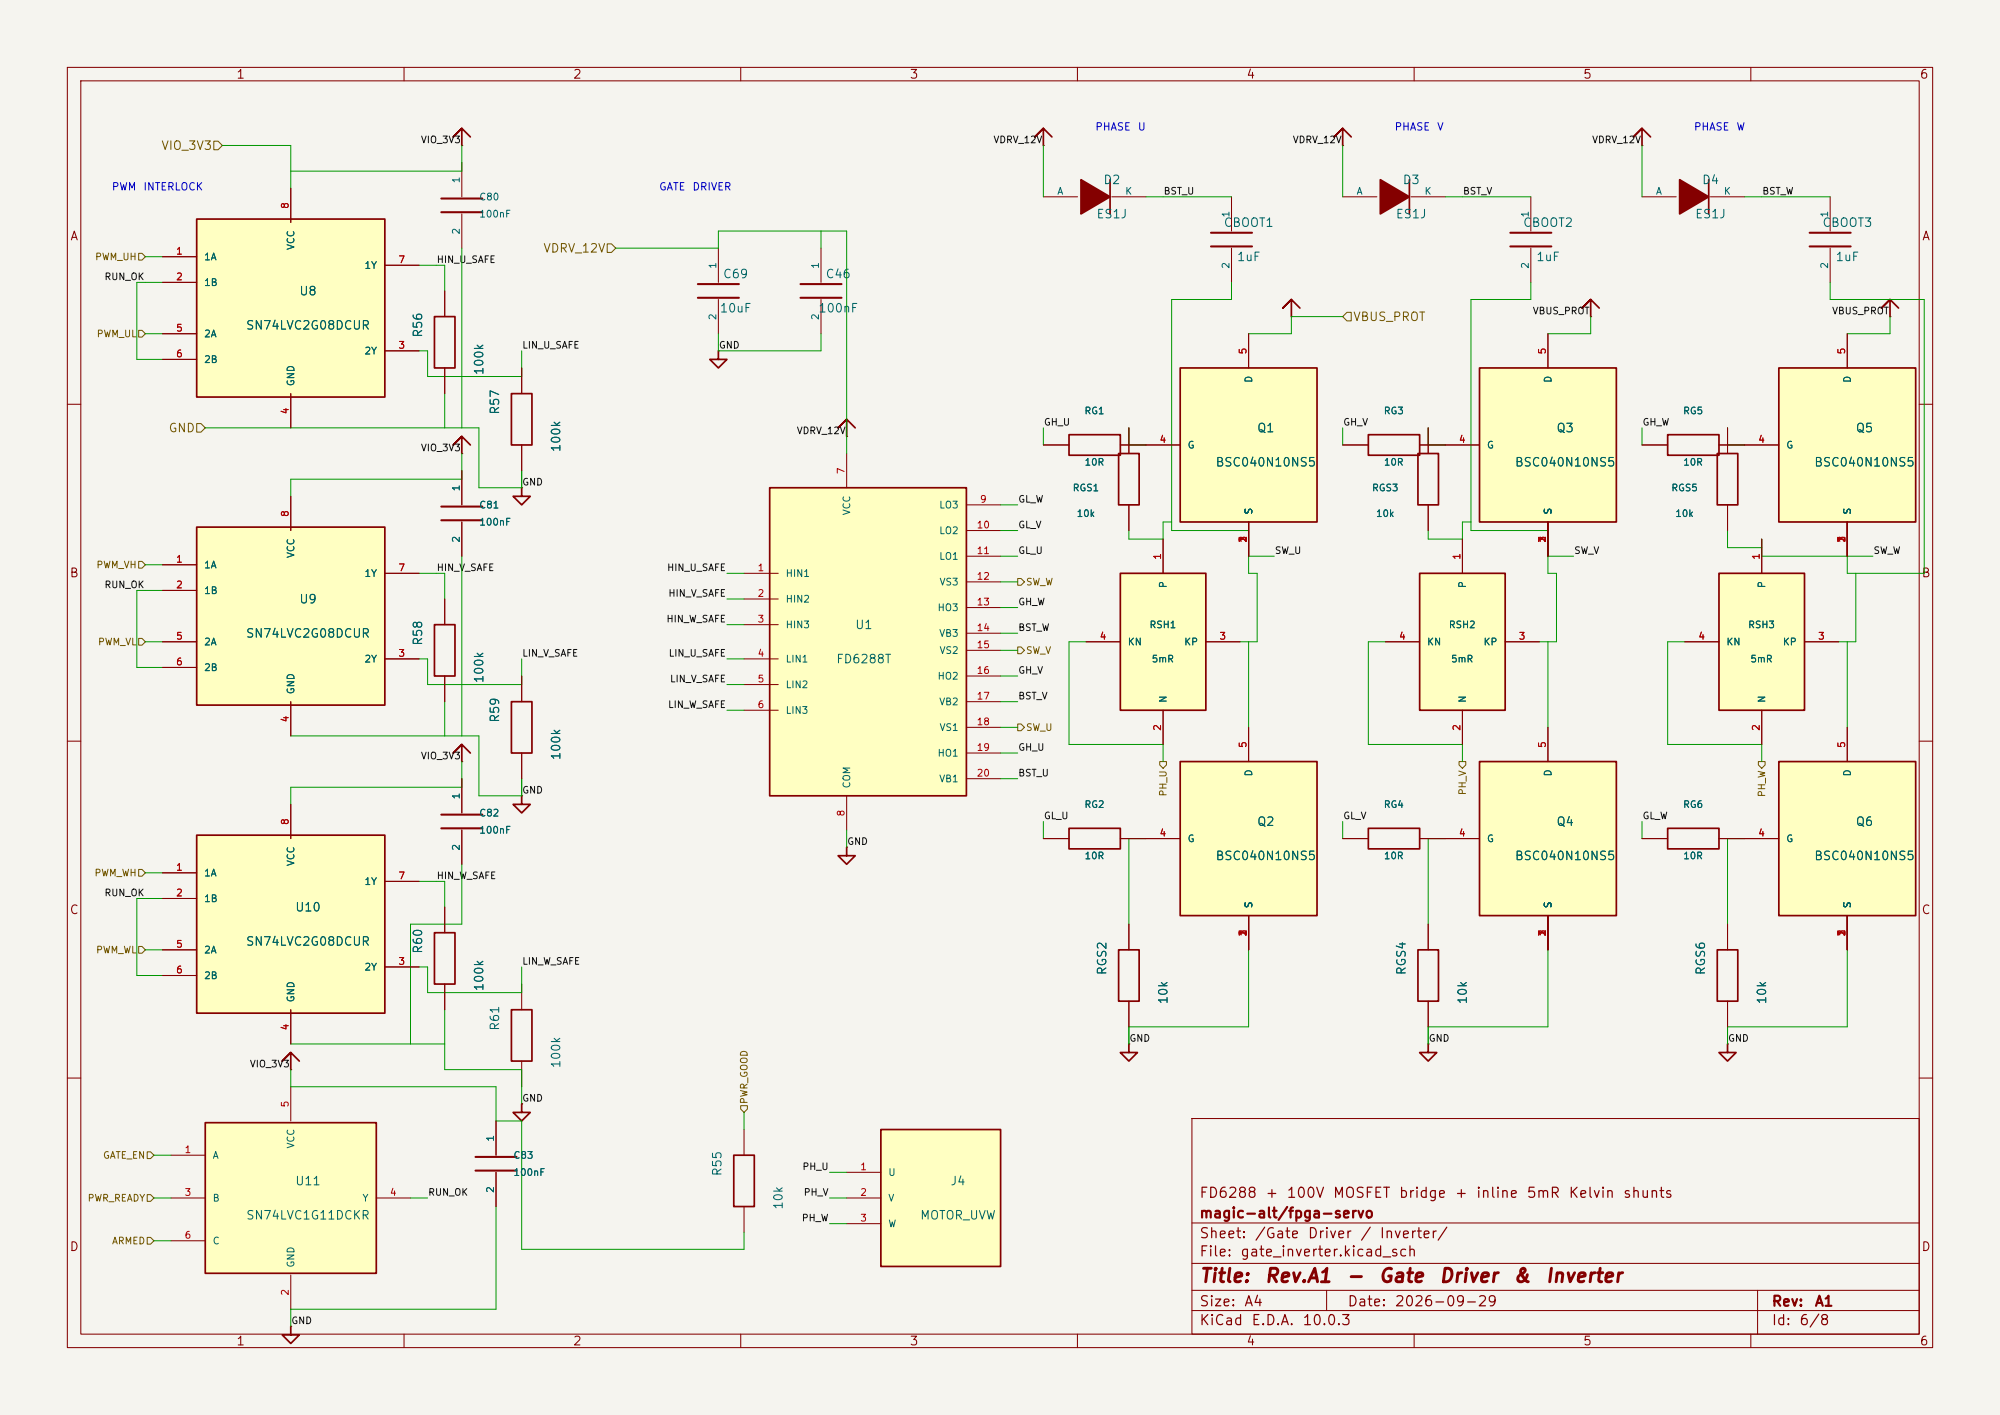
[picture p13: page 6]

FD6288 + 100V MOSFET bridge + inline 5mR Kelvin shunts
magic-alt/fpga-servo
Sheet: /Gate Driver / Inverter/
File: gate_inverter.kicad_sch
Title: Rev.A1 - Gate Driver & Inverter

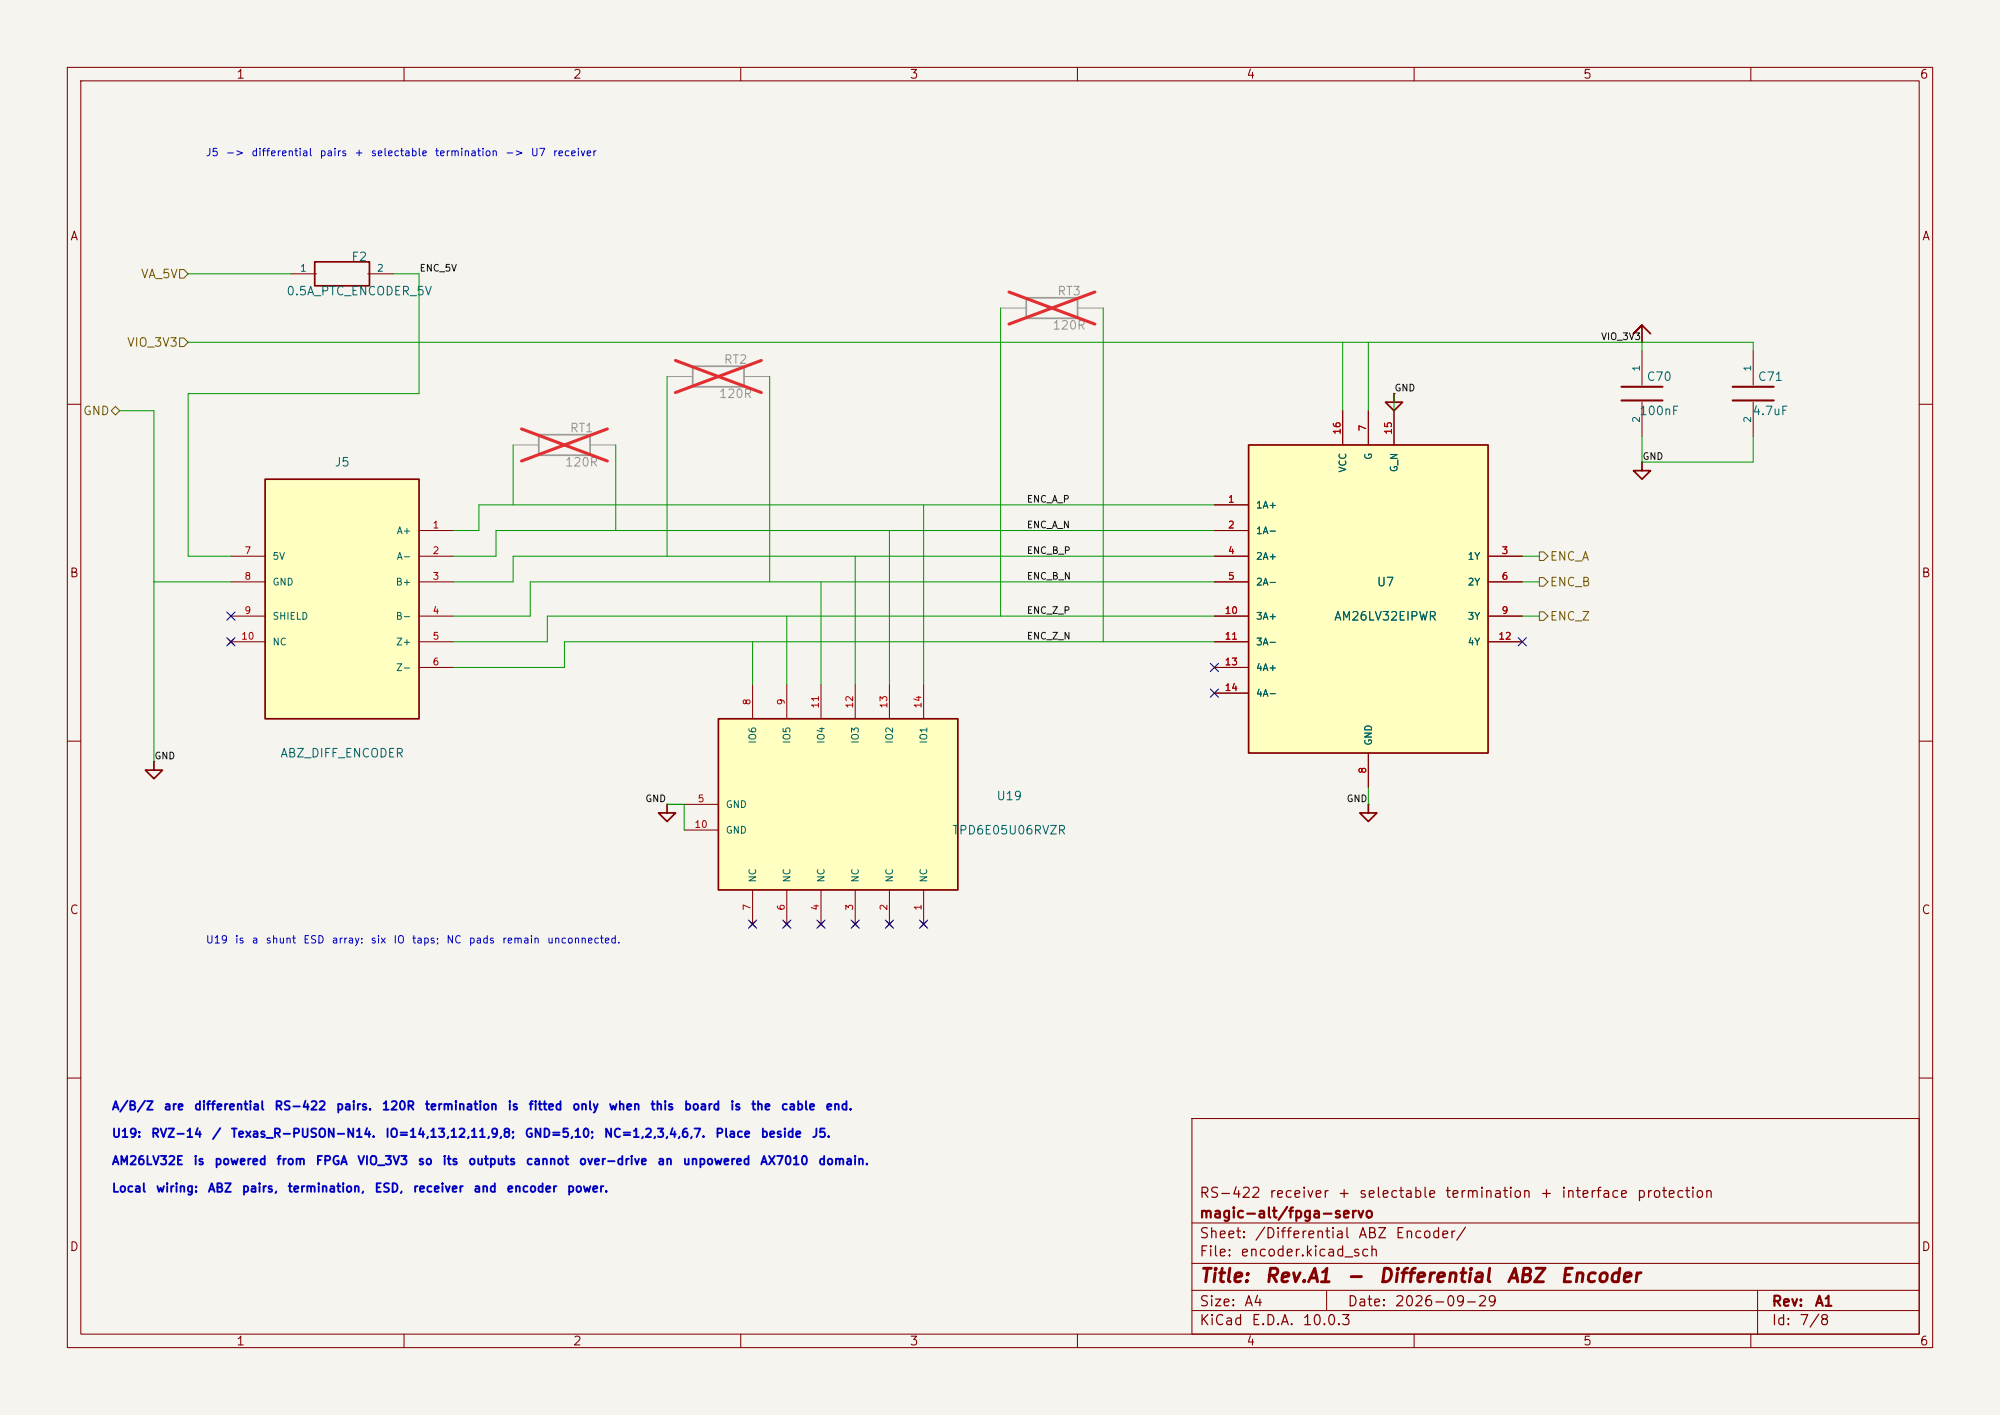
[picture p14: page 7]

5V 7 GND 8 | | | | 2A- 5

ENC_Z_P | | 3A+ 10

ENC_Z_N

RS-422 receiver + selectable termination + interface protection
magic-alt/fpga-servo
Sheet: /Differential ABZ Encoder/
File: encoder.kicad_sch
Title: Rev.A1 - Differential ABZ Encoder

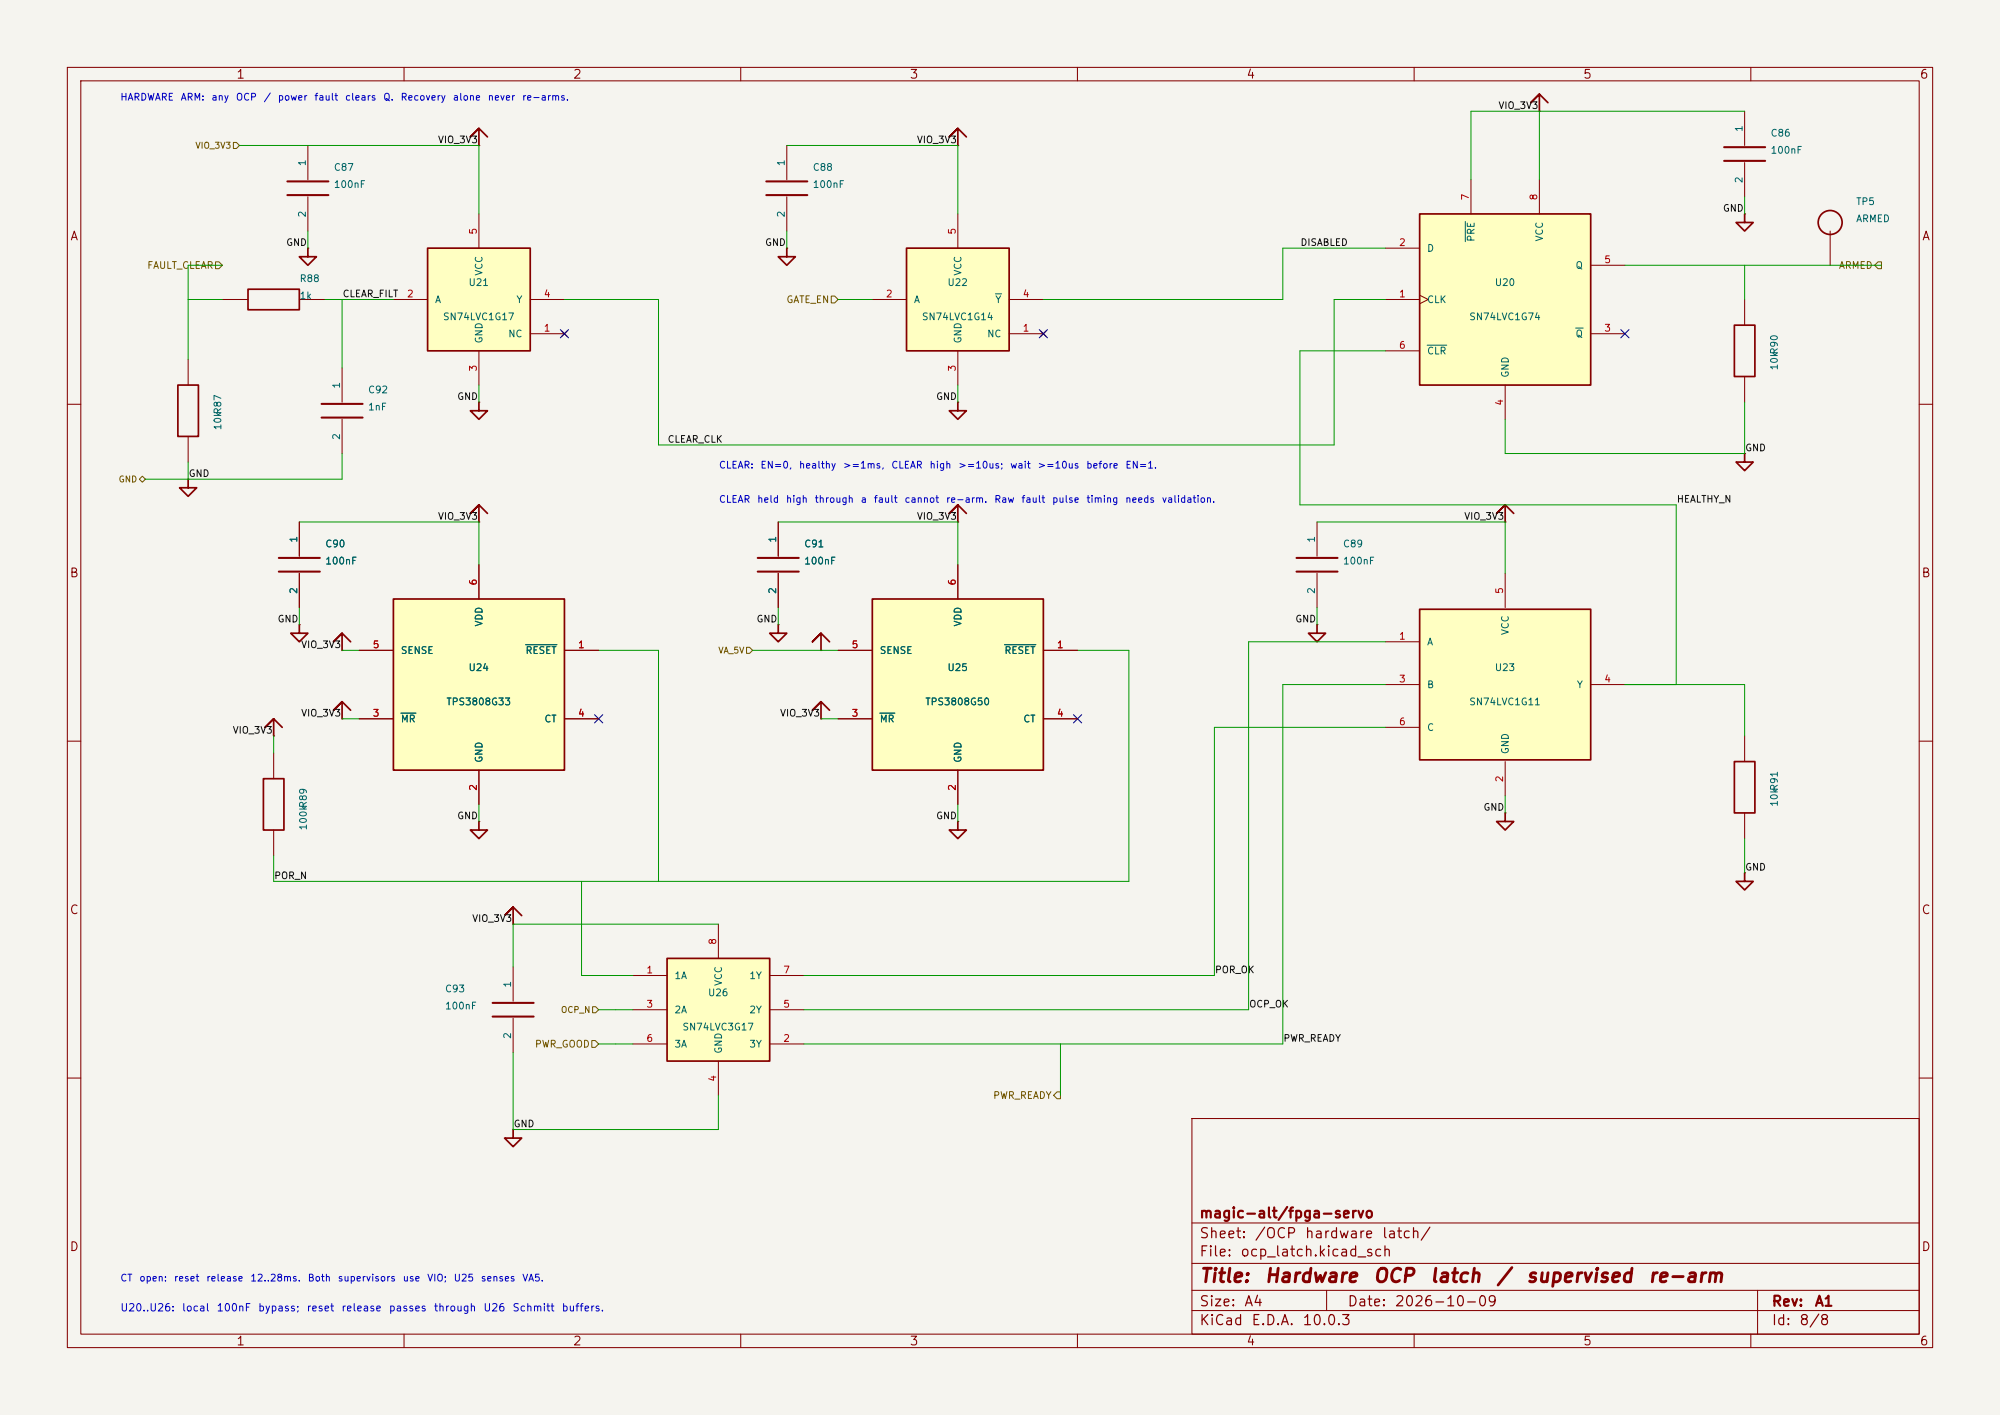
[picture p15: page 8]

magic-alt/fpga-servo
Sheet: /OCP hardware latch/
File: ocp_latch.kicad_sch
Title: Hardware OCP latch / supervised re-arm

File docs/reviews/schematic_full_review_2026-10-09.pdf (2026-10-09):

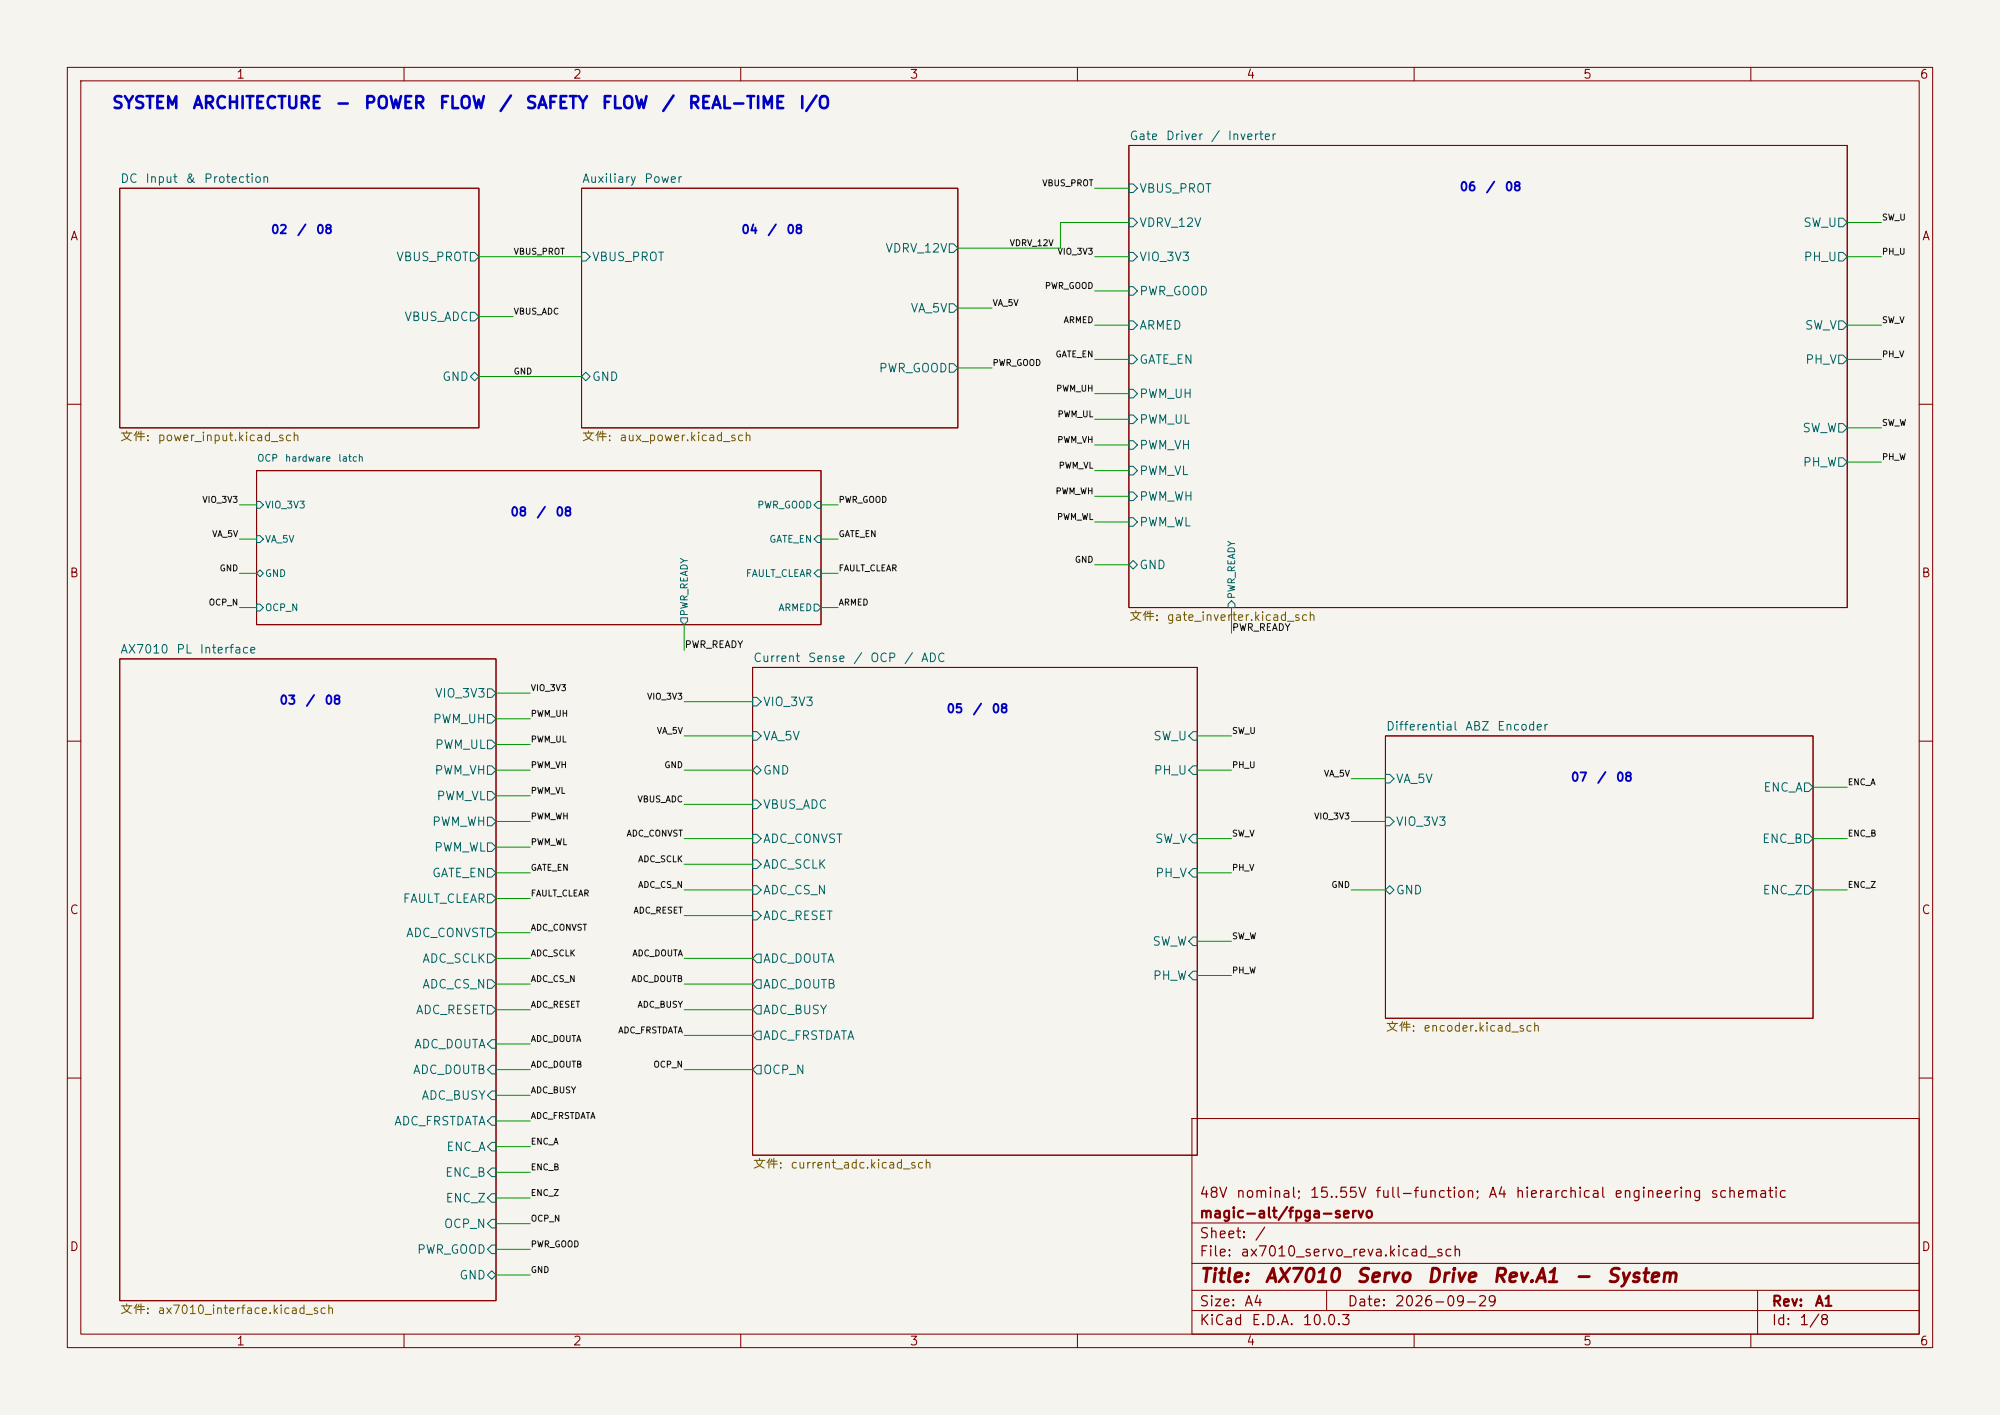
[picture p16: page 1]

PH_W PWR_READY Gate Driver / Inverter 文件: gate_inverter.kicad_sch
PWM_WL VDRV_12V PWR_GOOD

DC Input & Protection 文件: power_input.kicad_sch

ARMED
Current Sense / OCP / ADC 文件: current_adc.kicad_sch

ENC_Z Differential ABZ Encoder 文件: encoder.kicad_sch

48V nominal; 15..55V full-function; A4 hierarchical engineering schematic
magic-alt/fpga-servo
Sheet: /
File: ax7010_servo_reva.kicad_sch
Title: AX7010 Servo Drive Rev.A1 - System

Size: A4 | Rev: A1
KiCad E.D.A. 10.0.3 | Id: 1/8

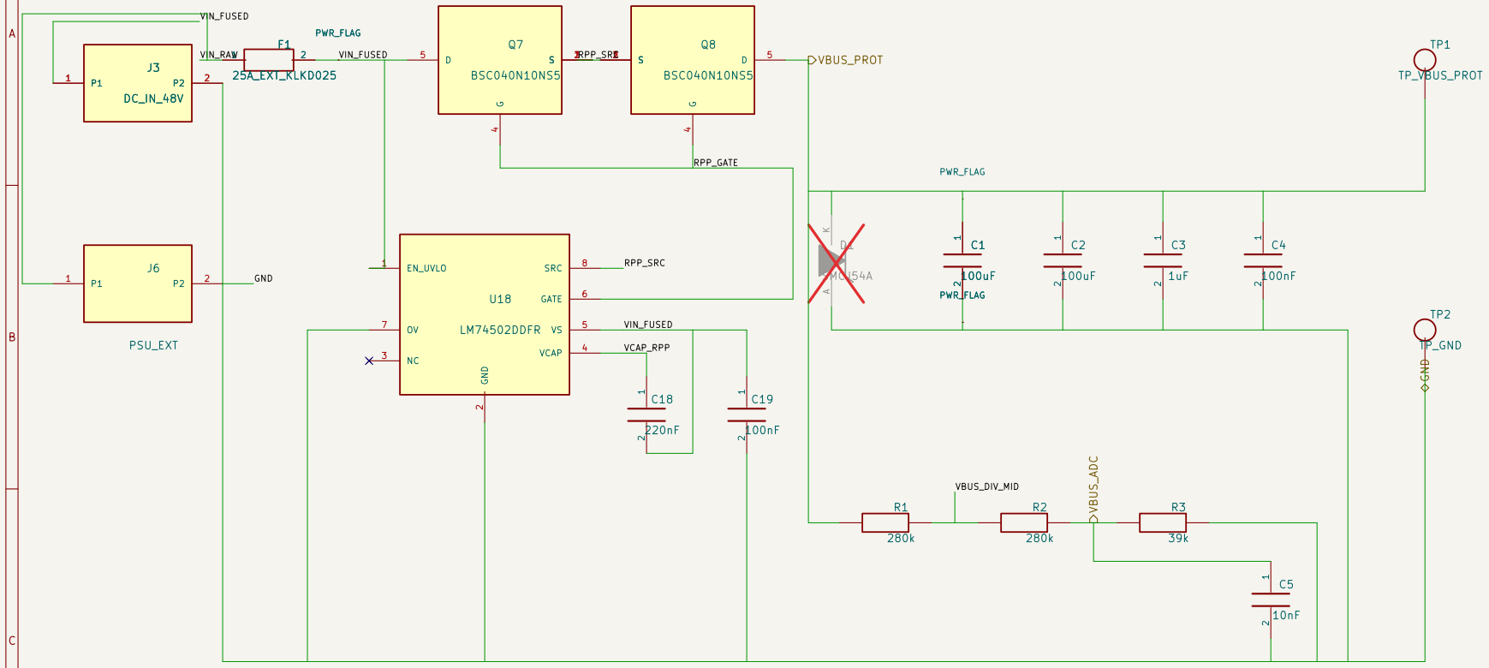
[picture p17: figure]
PWR_FLAG; EN_UVLO 1; GND; 2 NC 3 VCAP 4; 5 GATE; SRC; LM74502DDFR; TP_GND; TP_VBUS_PROT R2; 2 J6 PSU_EXT; PWR_FLAG A K D1; SMCJ54A; 25A_EXT_KLKD025; Q7 BSC040N10NS5; 5 Q8 BSC040N10NS5; VBUS_PROT; GND VBUS_ADC; RPP_SRC; VIN_FUSED; VBUS_DIV_MID; VIN_RAW; RPP_GATE; PWR_FLAG C1; PWR_FLAG F1

D

AB

C

## D Date: 2026-09-29

# Title: Rev.A1 - DC Input & Protection

## File: power_input.kicad_sch

## Sheet: /DC Input & Protection/

magic-alt/fpga-servo

## 48V-class bus; 15..55V design window; source transient qualification required

## VCAP_RPP SOURCE + -> EXTERNAL F1 -> J3.1 -> LM74502 RPP -> DC-LINK

F1: EXTERNAL KLKD025.T + LPSM0001Z, source + to J3.1. No PCB fuse. Verify fault-current, inrush and thermal coordination. D1 stays DNP pending surge qualification.

Q7/Q8 are back-to-back N-MOSFETs driven by LM74502 for low-loss reverse-polarity protection. The controller has no reverse-current blocking when enabled, so regeneration can return to a receptive source. Local wiring: power, gate, divider/filter and ground. See docs/schematic_full_review_2026-10-09.md.

LM74502 OV is tied low in Rev.A1; positive surge is NOT claimed as closed. The 48V source/cable transient must be measured and kept inside the controller/downstream qualification envelope.

VBUS_ADC divider = 280k + 280k over 39k, plus 10nF at the ADC node. Keep the high-side resistors split for voltage stress and route the sense return away from commutation current.

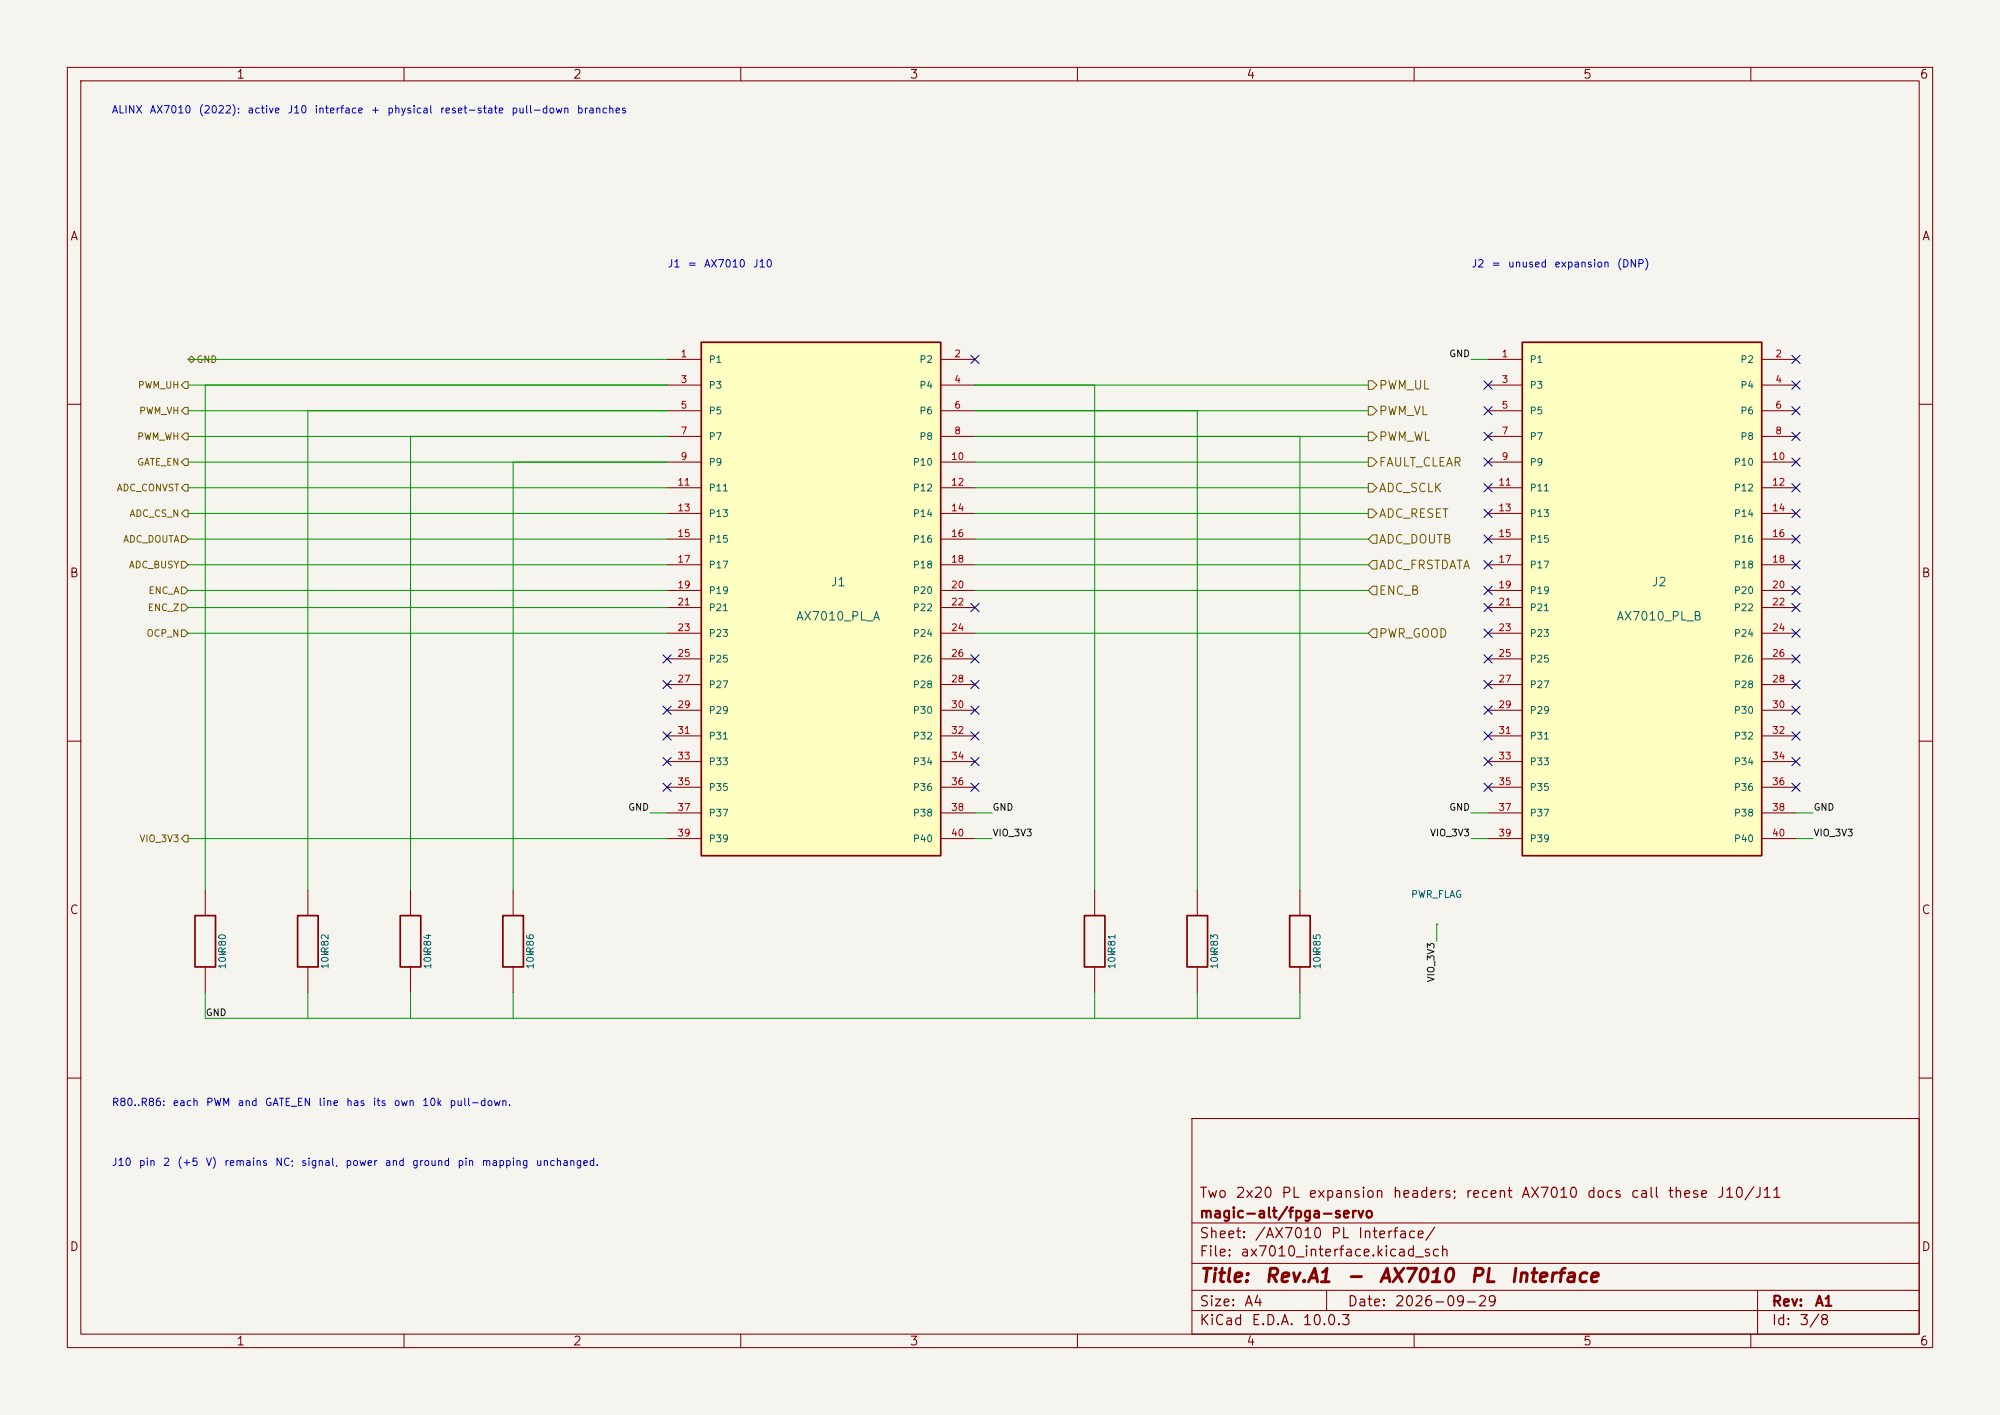
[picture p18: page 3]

ALINX AX7010 (2022): active J10 interface + physical reset-state pull-down branches

R80..R86: each PWM and GATE_EN line has its own 10k pull-down.

J10 pin 2 (+5 V) remains NC; signal, power and ground pin mapping unchanged.

magic-alt/fpga-servo
Sheet: /AX7010 PL Interface/
File: ax7010_interface.kicad_sch
Title: Rev.A1 - AX7010 PL Interface

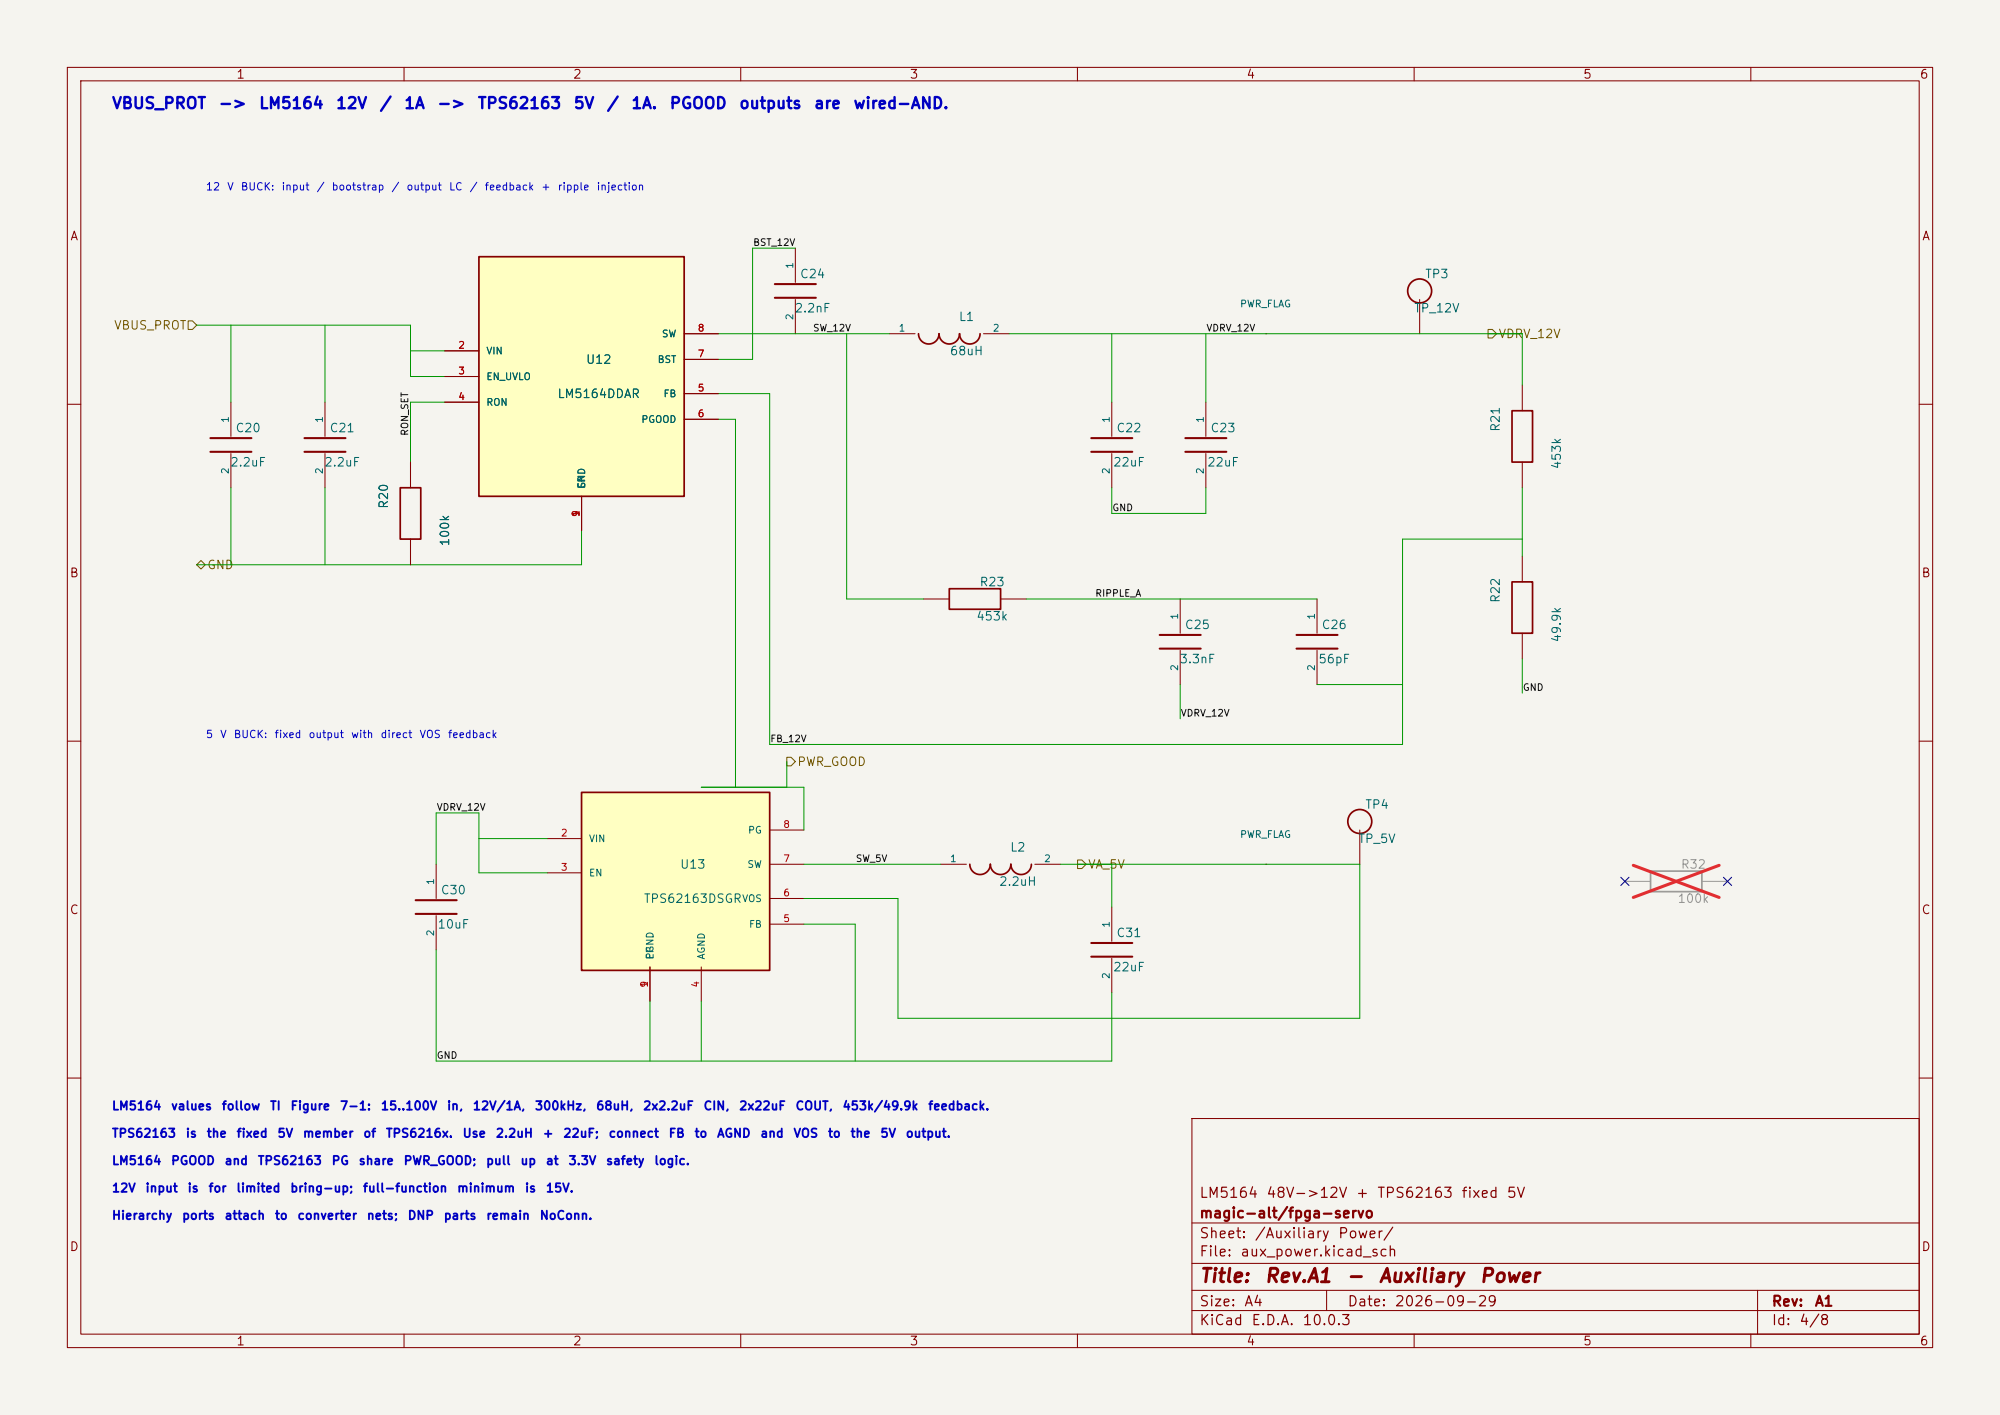
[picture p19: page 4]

12 V BUCK: input / bootstrap / output LC / feedback + ripple injection

TPS62163 is the fixed 5V member of TPS6216x. Use 2.2uH + 22uF; connect FB to AGND and VOS to the 5V output. 5 V BUCK: fixed output with direct VOS feedback LM5164 PGOOD and TPS62163 PG share PWR_GOOD; pull up at 3.3V safety logic.

Hierarchy ports attach to converter nets; DNP parts remain NoConn. LM5164 values follow TI Figure 7-1: 15..100V in, 12V/1A, 300kHz, 68uH, 2x2.2uF CIN, 2x22uF COUT, 453k/49.9k feedback.

12V input is for limited bring-up; full-function minimum is 15V.

LM5164 48V->12V + TPS62163 fixed 5V
magic-alt/fpga-servo
Sheet: /Auxiliary Power/
File: aux_power.kicad_sch
Title: Rev.A1 - Auxiliary Power


6 STBY 7 RANGE 8 CONVSTA 9 CONVSTB 10 RESET 11 RD_SCLK 12 CS 13 BUSY 14

3x INA241A2 + independent TLV9024 window OCP + ADS8588S
magic-alt/fpga-servo
Sheet: /Current Sense / OCP / ADC/
File: current_adc.kicad_sch
Title: Rev.A1 - Current Sense, OCP & ADC


FD6288 + 100V MOSFET bridge + inline 5mR Kelvin shunts
magic-alt/fpga-servo
Sheet: /Gate Driver / Inverter/
File: gate_inverter.kicad_sch
Title: Rev.A1 - Gate Driver & Inverter


J5 -> differential pairs + selectable termination -> U7 receiver

5V 7 GND 8 | | | ENC_B_N | 2A- 5

ENC_B_P | | 2A+ 4

ENC_Z_P | | 3A+ 10

ENC_Z_N

AM26LV32E is powered from FPGA VIO_3V3 so its outputs cannot over-drive an unpowered AX7010 domain. U19: RVZ-14 / Texas_R-PUSON-N14. IO=14,13,12,11,9,8; GND=5,10; NC=1,2,3,4,6,7. Place beside J5. A/B/Z are differential RS-422 pairs. 120R termination is fitted only when this board is the cable end. U19 is a shunt ESD array: six IO taps; NC pads remain unconnected. Local wiring: ABZ pairs, termination, ESD, receiver and encoder power.

RS-422 receiver + selectable termination + interface protection
magic-alt/fpga-servo
Sheet: /Differential ABZ Encoder/
File: encoder.kicad_sch
Title: Rev.A1 - Differential ABZ Encoder

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

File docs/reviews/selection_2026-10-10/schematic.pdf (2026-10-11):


06 / 08 SYSTEM ARCHITECTURE - POWER FLOW / SAFETY FLOW / REAL-TIME I/O

PH_W PWR_READY Gate Driver / Inverter File: gate_inverter.kicad_sch
VBUS_BRIDGE PWM_UH

Current Sense / OCP / ADC

ENC_Z Differential ABZ Encoder File: encoder.kicad_sch

24..48V bus; 10A continuous phase; 20kHz PWM; peak/thermal qualification OPEN
magic-alt/fpga-servo
Sheet: /
File: ax7010_servo_reva.kicad_sch
Title: AX7010 Servo Drive Rev.A1 - System

Size: A4 | Rev: A1
KiCad E.D.A. 10.0.3 | Id: 1/8

5 Q8 BSC040N10NS5; SMCJ54A; PWR_FLAG; 2 J6 PSU_EXT; Q7 BSC040N10NS5; EN_UVLO 1; GND; 2 NC 3 VCAP 4; 5 GATE; SRC; LM74502DDFR; VBUS_PROT; VBUS_ADC; RPP_SRC; RPP_GATE GND; VBUS_DIV_MID; VCAP_RPP; VIN_FUSED; 2 PWR_FLAG; PWR_FLAG C1

D

AB

C

## D Date: 2026-09-29

# Title: Rev.A1 - DC Input & Protection

## File: power_input.kicad_sch

## Sheet: /DC Input & Protection/

## magic-alt/fpga-servo

## 24..48V operating bus; source transient / regeneration qualification OPEN

TP2

### TP_GND

TP1

### TP_VBUS_PROT

VIN_RAW | VIN_FUSED Q7/Q8 are back-to-back N-MOSFETs driven by LM74502 for low-loss reverse-polarity protection. Reverse current is not blocked when enabled; regeneration needs a receptive source. F1: ONBOARD 0456025.ER 25A SMD. Verify fault current, inrush and thermal coordination. D1 stays DNP pending surge qualification.

VBUS_ADC divider = 280k + 280k over 39k, plus 10nF at the ADC node. Keep the high-side resistors split for voltage stress and route the sense return away from commutation current. LM74502 OV is tied low in Rev.A1; positive surge is NOT claimed as closed. The 48V source/cable transient must be measured and kept inside the controller/downstream qualification envelope. Local wiring: power, gate, divider/filter and ground. See docs/schematic_full_review_2026-10-09.md.

## SOURCE + -> J3.1 -> ONBOARD F1 -> LM74502 RPP -> DC-LINK


ALINX AX7010 (2022): active J10 interface + physical reset-state pull-down branches

R80..R86: each PWM and GATE_EN line has its own 10k pull-down.

J10 pin 2 (+5 V): NC. J2 removed; only J1 interfaces to AX7010.

magic-alt/fpga-servo
Sheet: /AX7010 PL Interface/
File: ax7010_interface.kicad_sch
Title: Rev.A1 - AX7010 PL Interface


VBUS_PROT -> LM5164 12V -> TPS62901 5.1V. Rail load / transient qualification OPEN. U12

12 V BUCK: input / bootstrap / output LC / feedback + ripple injection

VDRV_12V 5 V BUCK: precision external FB; forced PWM 2.5MHz

LM5164 values follow TI Figure 7-1: 15..100V in, 12V/1A, 300kHz, 68uH, 2x2.2uF CIN, 2x22uF COUT, 453k/49.9k feedback. LM5164 PGOOD and TPS62901 PG share PWR_GOOD; pull up at 3.3V safety logic. PGOOD alone does not prove VA5 valid; U25 separately monitors VA5. System operating input: 24..48V. Low-voltage bring-up is separately qualified. TPS62901: 5.1V nominal; FB=75k/10k; MODE=VIN: forced PWM 2.5MHz. VOS to output.

LM5164 48V->12V + TPS62901 precision 5.1V
magic-alt/fpga-servo
Sheet: /Auxiliary Power/
File: aux_power.kicad_sch
Title: Rev.A1 - Auxiliary Power


ADC / SERIAL INTERFACE CURRENT SENSE + RC FILTER

Bridge bus shunt after DC-link capacitors BUS OCP: +25A NOMINAL

6 STBY 7 RANGE 8 CONVSTA 9 CONVSTB 10 RESET 11 RD_SCLK 12 CS 13 BUSY 14

No reverse-current trip; latch requires explicit re-arm

3 phase ADC channels + independent +25A bus OCP / hardware latch
magic-alt/fpga-servo
Sheet: /Current Sense / OCP / ADC/
File: current_adc.kicad_sch
Title: Rev.A1 - Current Sense, OCP & ADC


DRV8300DP internal bootstrap + 100V MOSFET bridge + inline 5mR phase shunts
magic-alt/fpga-servo
Sheet: /Gate Driver / Inverter/
File: gate_inverter.kicad_sch
Title: Rev.A1 - Gate Driver & Inverter


5V 7 GND 8 | ENC_B_N | 2A- 5

ENC_Z_N

RS-422 receiver + selectable termination + interface protection
magic-alt/fpga-servo
Sheet: /Differential ABZ Encoder/
File: encoder.kicad_sch
Title: Rev.A1 - Differential ABZ Encoder


CLEAR held high through a fault cannot re-arm. Raw fault pulse timing needs validation. CLEAR: EN=0, healthy >=1ms, CLEAR high >=10us; wait >=10us before EN=1. HARDWARE ARM: any OCP / power fault clears Q. Recovery alone never re-arms. U24

Sheet: /OCP hardware latch/
File: ocp_latch.kicad_sch
Title: Hardware OCP latch / supervised re-arm
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

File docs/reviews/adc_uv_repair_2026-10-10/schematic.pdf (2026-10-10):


PH_W PWR_READY Gate Driver / Inverter 文件: gate_inverter.kicad_sch
PWM_WL VDRV_12V PWR_GOOD

DC Input & Protection 文件: power_input.kicad_sch

ARMED
Current Sense / OCP / ADC 文件: current_adc.kicad_sch

ENC_Z Differential ABZ Encoder 文件: encoder.kicad_sch

48V nominal; 15..55V full-function; A4 hierarchical engineering schematic
magic-alt/fpga-servo
Sheet: /
File: ax7010_servo_reva.kicad_sch
Title: AX7010 Servo Drive Rev.A1 - System

Size: A4 | Rev: A1
KiCad E.D.A. 10.0.3 | Id: 1/8


SOURCE + -> EXTERNAL F1 -> J3.1 -> LM74502 RPP -> DC-LINK

48V-class bus; 15..55V design window; source transient qualification required
magic-alt/fpga-servo
Sheet: /DC Input & Protection/
File: power_input.kicad_sch
Title: Rev.A1 - DC Input & Protection


ALINX AX7010 (2022): active J10 interface + physical reset-state pull-down branches

J10 pin 2 (+5 V) remains NC; signal, power and ground pin mapping unchanged. R80..R86: each PWM and GATE_EN line has its own 10k pull-down.

magic-alt/fpga-servo
Sheet: /AX7010 PL Interface/
File: ax7010_interface.kicad_sch
Title: Rev.A1 - AX7010 PL Interface


12 V BUCK: input / bootstrap / output LC / feedback + ripple injection

VDRV_12V Hierarchy ports attach to converter nets; DNP parts remain NoConn. LM5164 PGOOD and TPS62901 PG share PWR_GOOD; pull up at 3.3V safety logic.

LM5164 48V->12V + TPS62901 precision 5.1V
magic-alt/fpga-servo
Sheet: /Auxiliary Power/
File: aux_power.kicad_sch
Title: Rev.A1 - Auxiliary Power


6 STBY 7 RANGE 8 CONVSTA 9 CONVSTB 10 RESET 11 RD_SCLK 12 CS 13 BUSY 14

3x INA241A2 + independent TLV9024 window OCP + ADS8588S
magic-alt/fpga-servo
Sheet: /Current Sense / OCP / ADC/
File: current_adc.kicad_sch
Title: Rev.A1 - Current Sense, OCP & ADC


FD6288 + 100V MOSFET bridge + inline 5mR Kelvin shunts
magic-alt/fpga-servo
Sheet: /Gate Driver / Inverter/
File: gate_inverter.kicad_sch
Title: Rev.A1 - Gate Driver & Inverter


5V 7 GND 8 | | | | 2A- 5

ENC_Z_P | | 3A+ 10

ENC_Z_N

RS-422 receiver + selectable termination + interface protection
magic-alt/fpga-servo
Sheet: /Differential ABZ Encoder/
File: encoder.kicad_sch
Title: Rev.A1 - Differential ABZ Encoder


VIO_3V3 HARDWARE ARM: any OCP / power fault clears Q. Recovery alone never re-arms.

CLEAR: EN=0, healthy >=1ms, CLEAR high >=10us; wait >=10us before EN=1. CLEAR held high through a fault cannot re-arm. Raw fault pulse timing needs validation. U24

magic-alt/fpga-servo
Sheet: /OCP hardware latch/
File: ocp_latch.kicad_sch
Title: Hardware OCP latch / supervised re-arm

U24 CT open: 12..28ms. U25 CT=100nF: ~107ms; VA5 trip nominal 4.876V. Dynamic qualification OPEN. U20..U26: local 100nF bypass; reset release passes through U26 Schmitt buffers.

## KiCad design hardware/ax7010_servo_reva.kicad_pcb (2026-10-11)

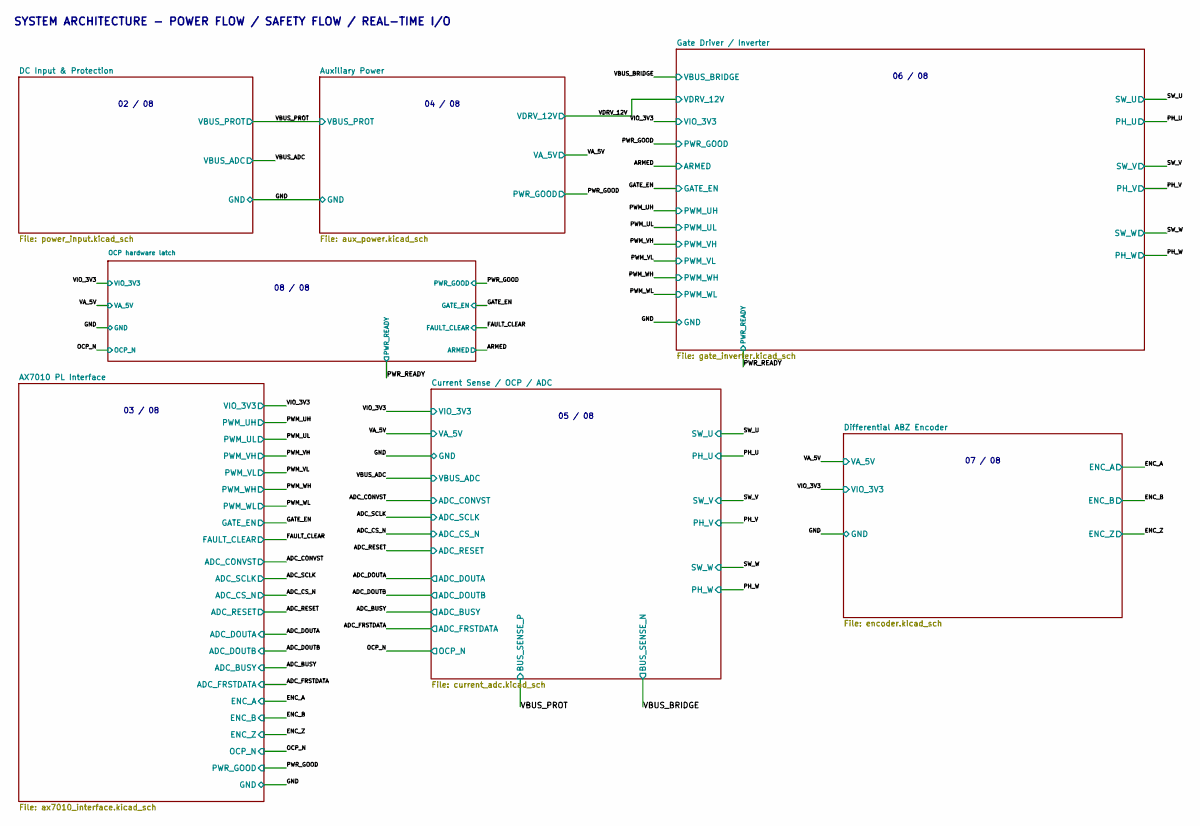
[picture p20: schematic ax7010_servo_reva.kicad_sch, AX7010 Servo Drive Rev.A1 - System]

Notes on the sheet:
SYSTEM ARCHITECTURE - POWER FLOW / SAFETY FLOW / REAL-TIME I/O
02 / 08
04 / 08
06 / 08
03 / 08
05 / 08
07 / 08
08 / 08

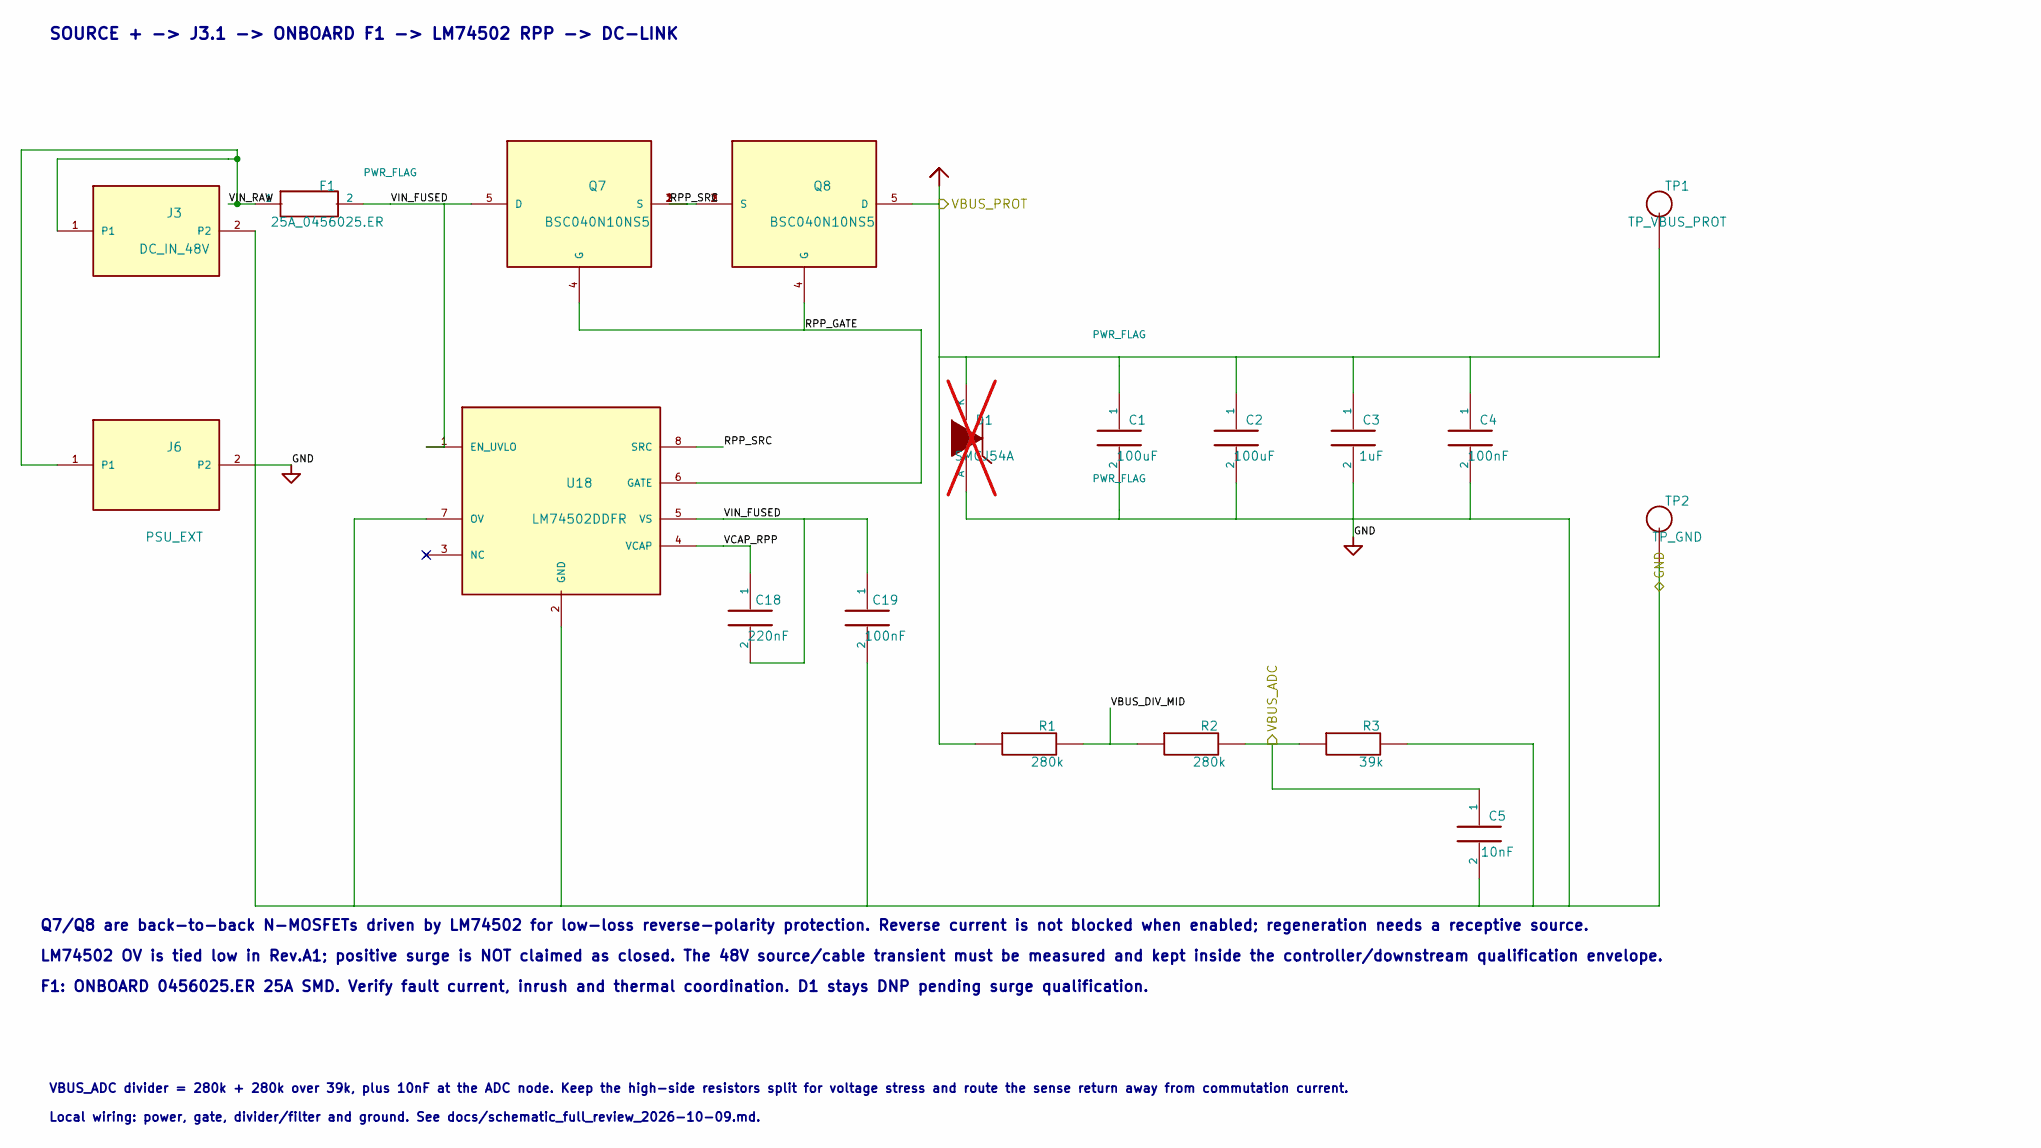
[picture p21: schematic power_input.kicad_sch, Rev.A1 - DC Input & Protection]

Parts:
C1, C2: 100uF; CP_Radial_D10.0mm_P5.00mm; MPN EKZN101ELL101MJ20S; LCSC C337258
C3: 1uF; C_Rect_L18.0mm_W8.0mm_P15.00mm_FKS3_FKP3; MPN C212E105J6BC000; LCSC C604836
C4: 100nF; C_1812_4532Metric; MPN C4532C0G2A104JT000N; LCSC C342611
C5: 10nF; C_0603_1608Metric; MPN 0603B103K101NT; LCSC C43253
C18: 220nF; C_0805_2012Metric; MPN 0805B224K500NT; LCSC C163697
C19: 100nF; C_0805_2012Metric; MPN 0805B104K101NT; LCSC C89258
D1: SMCJ54A; D_SMC; not fitted
F1: 25A_0456025.ER; Littelfuse_456_25A_SMD; MPN 0456025.ER; LCSC C315877
J3: DC_IN_48V; PhoenixContact_MKDS_5_2_9.52mm; MPN 1714971; LCSC C92145
J6: PSU_EXT; MPN TBD
Q7, Q8: BSC040N10NS5; Infineon_PG-TDSON-8_6.15x5.15mm; MPN BSC040N10NS5; LCSC C534334
R1, R2: 280k; R_0805_2012Metric; MPN PTFR0805B280KP9; LCSC C2849140
R3: 39k; R_0603_1608Metric; MPN TC0325B3902T5F; LCSC C2988897
TP1: TP_VBUS_PROT; TestPoint_Pad_D2.0mm
TP2: TP_GND; TestPoint_Pad_D2.0mm
U18: LM74502DDFR; TI_DDF0008A_SOT23_8_P0.65mm; MPN LM74502DDFR; LCSC C3236215

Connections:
/DC Input & Protection/RPP_GATE: Q7.4 (G), Q8.4 (G), U18.6 (GATE)
/DC Input & Protection/RPP_SRC: Q7.1 (S), Q7.2 (S), Q7.3 (S), Q8.1 (S), Q8.2 (S), Q8.3 (S), U18.8 (SRC)
/DC Input & Protection/VBUS_DIV_MID: R1.2, R2.1
/DC Input & Protection/VCAP_RPP: C18.1, U18.4 (VCAP)
/VBUS_ADC: C5.1, R2.2, R3.1; also elsewhere on the board
/VBUS_PROT: C1.1, C2.1, C3.1, C4.1, D1.1 (K), Q8.5 (D), R1.1, TP1.1; also elsewhere on the board

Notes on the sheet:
Local wiring: power, gate, divider/filter and ground. See docs/schematic_full_review_2026-10-09.md.
LM74502 OV is tied low in Rev.A1; positive surge is NOT claimed as closed. The 48V source/cable transient must be measured and kept inside the controller/downstream qualification envelope.
VBUS_ADC divider = 280k + 280k over 39k, plus 10nF at the ADC node. Keep the high-side resistors split for voltage stress and route the sense return away from commutation current.
F1: ONBOARD 0456025.ER 25A SMD. Verify fault current, inrush and thermal coordination. D1 stays DNP pending surge qualification.
Q7/Q8 are back-to-back N-MOSFETs driven by LM74502 for low-loss reverse-polarity protection. Reverse current is not blocked when enabled; regeneration needs a receptive source.
SOURCE + -> J3.1 -> ONBOARD F1 -> LM74502 RPP -> DC-LINK

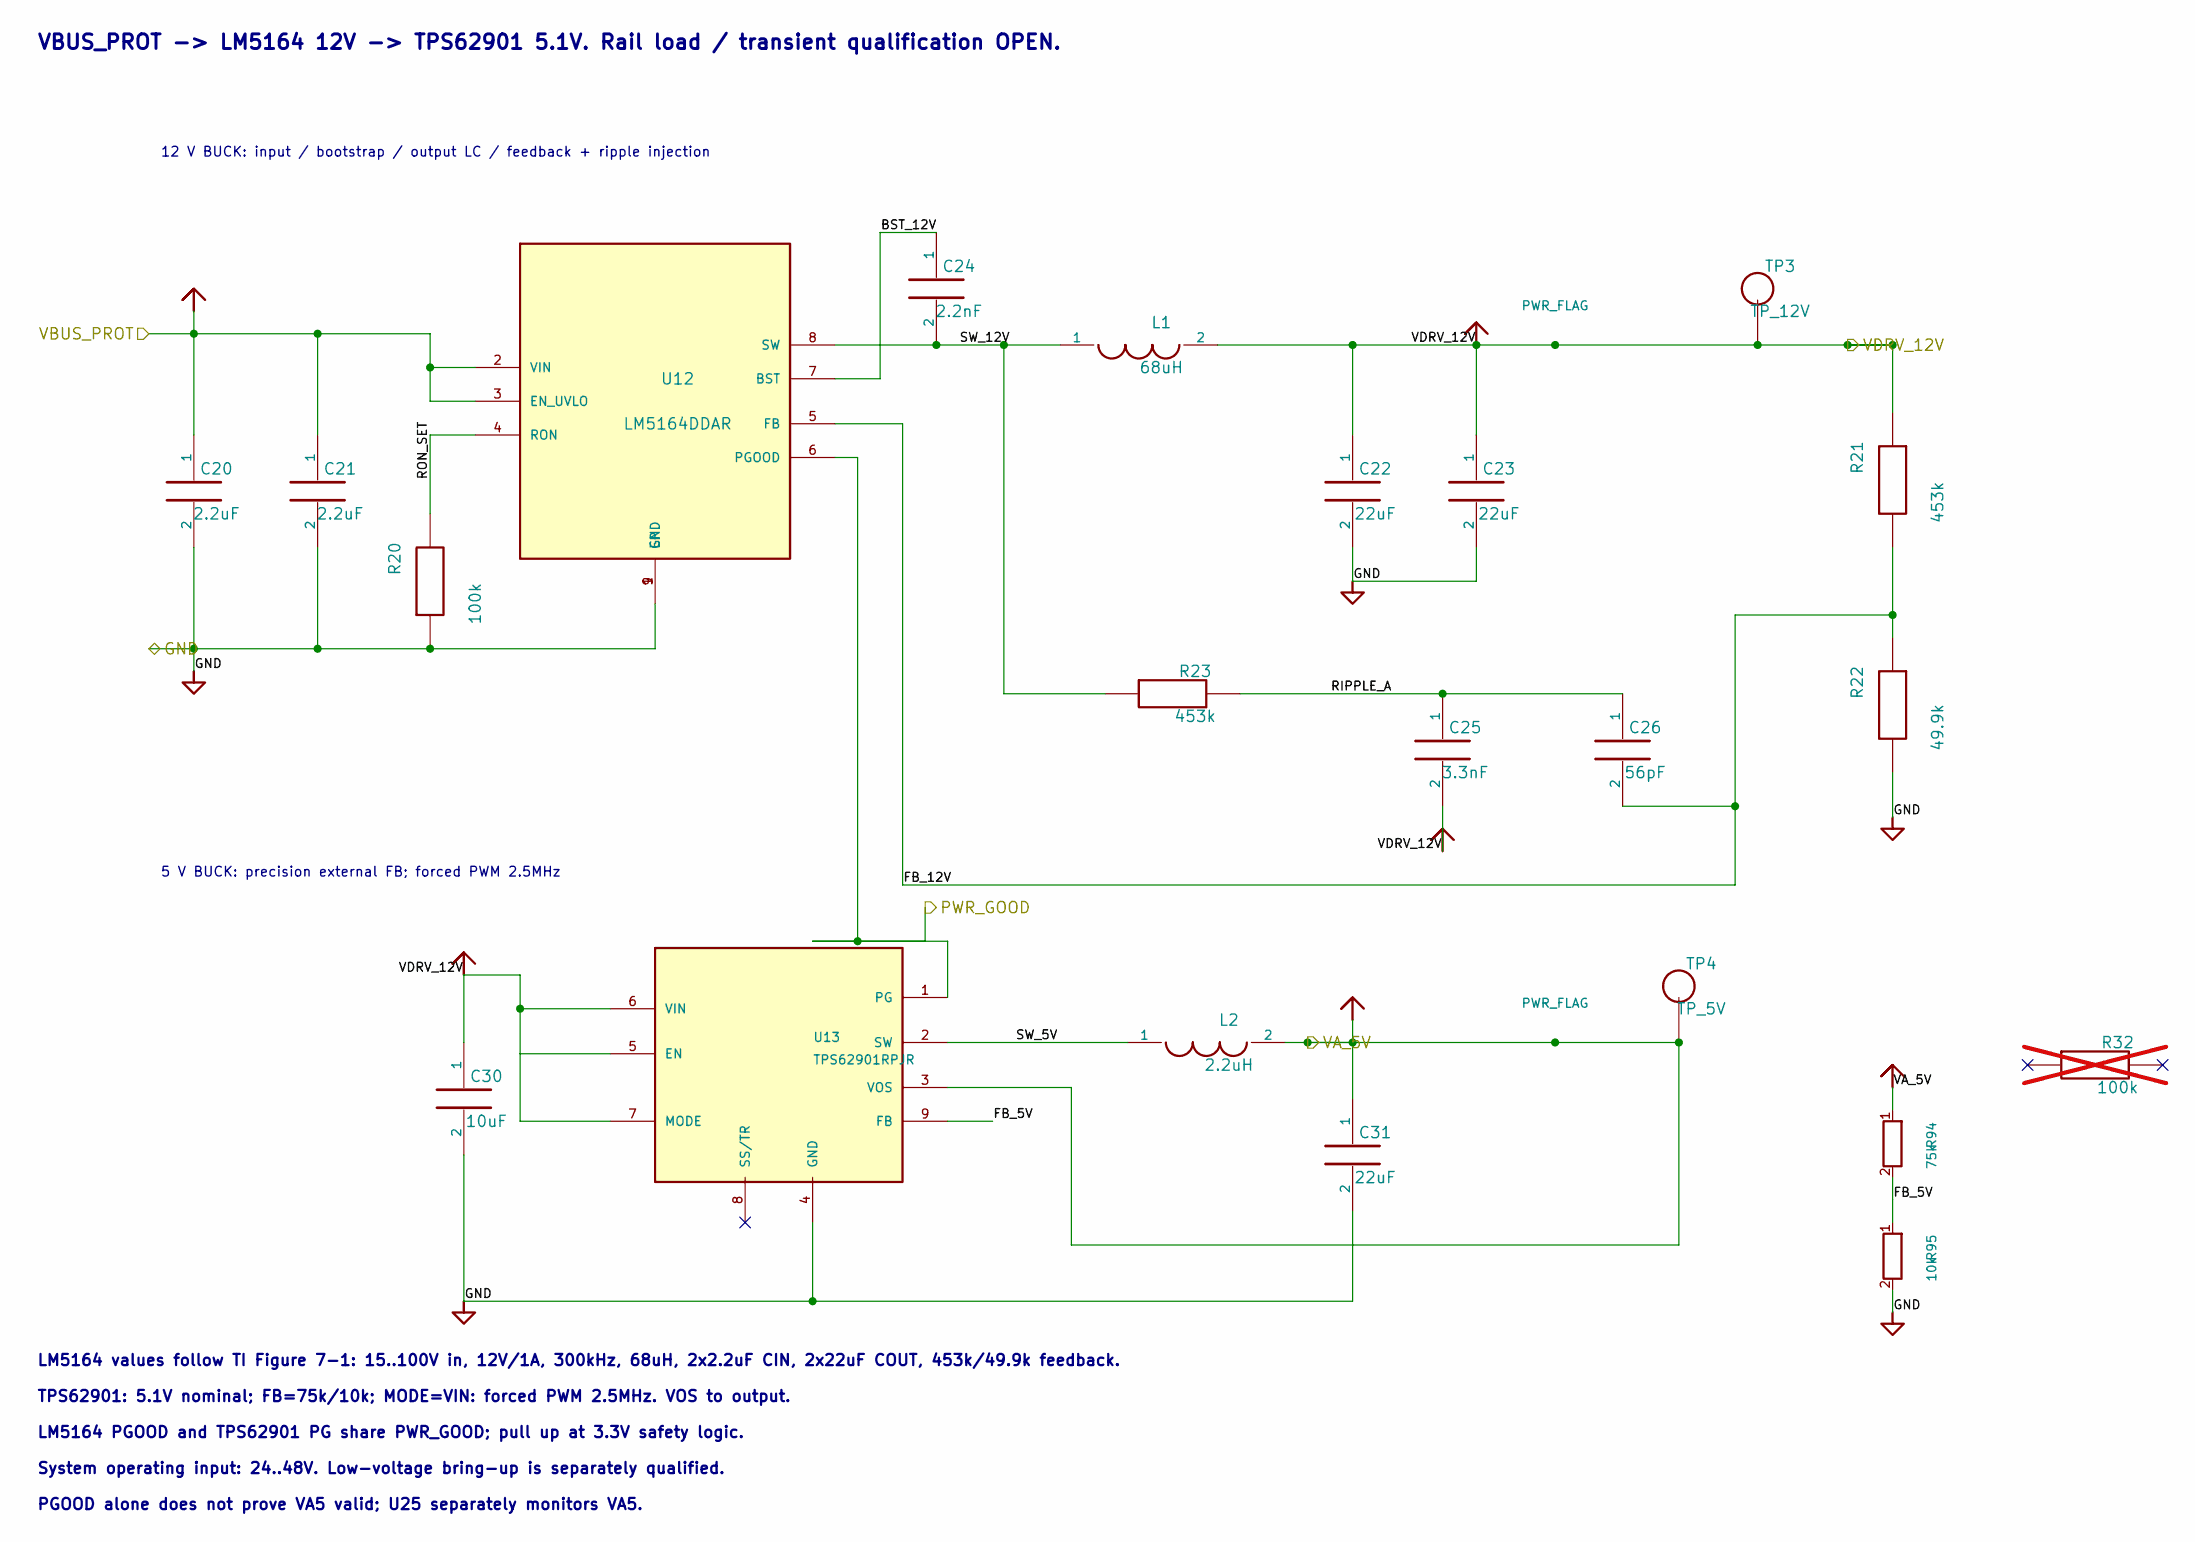
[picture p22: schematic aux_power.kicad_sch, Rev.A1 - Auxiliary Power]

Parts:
C20, C21: 2.2uF; C_1210_3225Metric; MPN 1210B225K101NT; LCSC C42400139
C22, C23: 22uF; C_1210_3225Metric; MPN 1210B226K250NT; LCSC C5204920
C24: 2.2nF; C_0603_1608Metric; MPN 0603B222J500NT; LCSC C60328
C25: 3.3nF; C_0603_1608Metric; MPN 0603B332J500NT; LCSC C20616243
C26: 56pF; C_0603_1608Metric; MPN 0603CG560J500NT; LCSC C1676
C30: 10uF; C_0805_2012Metric; MPN HGC0805R7106K250NSLJ; LCSC C33546010
C31: 22uF; C_0805_2012Metric; MPN CGA0805X7R226M100MT; LCSC C23692981
L1: 68uH; SOREDE_SDRH1209_68uH; MPN SDRH.1209.LF680MT00; LCSC C2942326
L2: 2.2uH; Sunlord_SWPA4020S; MPN SWPA4020S2R2MT; LCSC C83423
R20: 100k; R_0603_1608Metric; MPN 0603WAF1003T5E; LCSC C25803
R21, R23: 453k; R_0603_1608Metric; MPN RC0603FR-07453KL; LCSC C273765
R22: 49.9k; R_0603_1608Metric; MPN 0603WAF4992T5E; LCSC C23184
R32: 100k; R_0603_1608Metric; not fitted
R94: 75k; R_0603_1608Metric; Tolerance 0.05%; MPN PTFR0603Q75K0N9; LCSC C53280140
R95: 10k; R_0603_1608Metric; Tolerance 0.05%; MPN PTFR0603Q10K0N9; LCSC C51822132
TP3: TP_12V; TestPoint_Pad_D2.0mm
TP4: TP_5V; TestPoint_Pad_D2.0mm
U12: LM5164DDAR; TI_SO-PowerPAD-8; MPN LM5164DDAR; LCSC C477928
U13: TPS62901RPJR; Texas_RPJ0009A_VQFN-HR-9_1.5x2mm; MPN TPS62901RPJR; LCSC C2864847

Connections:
/Auxiliary Power/BST_12V: C24.1, U12.7 (BST)
/Auxiliary Power/FB_5V: R94.2, R95.1, U13.9 (FB)
/Auxiliary Power/FB_12V: C26.2, R21.2, R22.1, U12.5 (FB)
/Auxiliary Power/RIPPLE_A: C25.1, C26.1, R23.2
/Auxiliary Power/RON_SET: R20.2, U12.4 (RON)
/Auxiliary Power/SW_5V: L2.1, U13.2 (SW)
/Auxiliary Power/SW_12V: C24.2, L1.1, R23.1, U12.8 (SW)
/PWR_GOOD: U12.6 (PGOOD), U13.1 (PG); also elsewhere on the board
/VBUS_PROT: C20.1, C21.1, U12.2 (VIN), U12.3 (EN_UVLO); also elsewhere on the board
/VDRV_12V: C22.1, C23.1, C25.2, C30.1, L1.2, R21.1, TP3.1, U13.5 (EN), U13.6 (VIN), U13.7 (MODE); also elsewhere on the board

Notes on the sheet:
VBUS_PROT -> LM5164 12V -> TPS62901 5.1V. Rail load / transient qualification OPEN.
TPS62901: 5.1V nominal; FB=75k/10k; MODE=VIN: forced PWM 2.5MHz. VOS to output.
System operating input: 24..48V. Low-voltage bring-up is separately qualified.
PGOOD alone does not prove VA5 valid; U25 separately monitors VA5.
LM5164 PGOOD and TPS62901 PG share PWR_GOOD; pull up at 3.3V safety logic.
LM5164 values follow TI Figure 7-1: 15..100V in, 12V/1A, 300kHz, 68uH, 2x2.2uF CIN, 2x22uF COUT, 453k/49.9k feedback.
12 V BUCK: input / bootstrap / output LC / feedback + ripple injection
5 V BUCK: precision external FB; forced PWM 2.5MHz

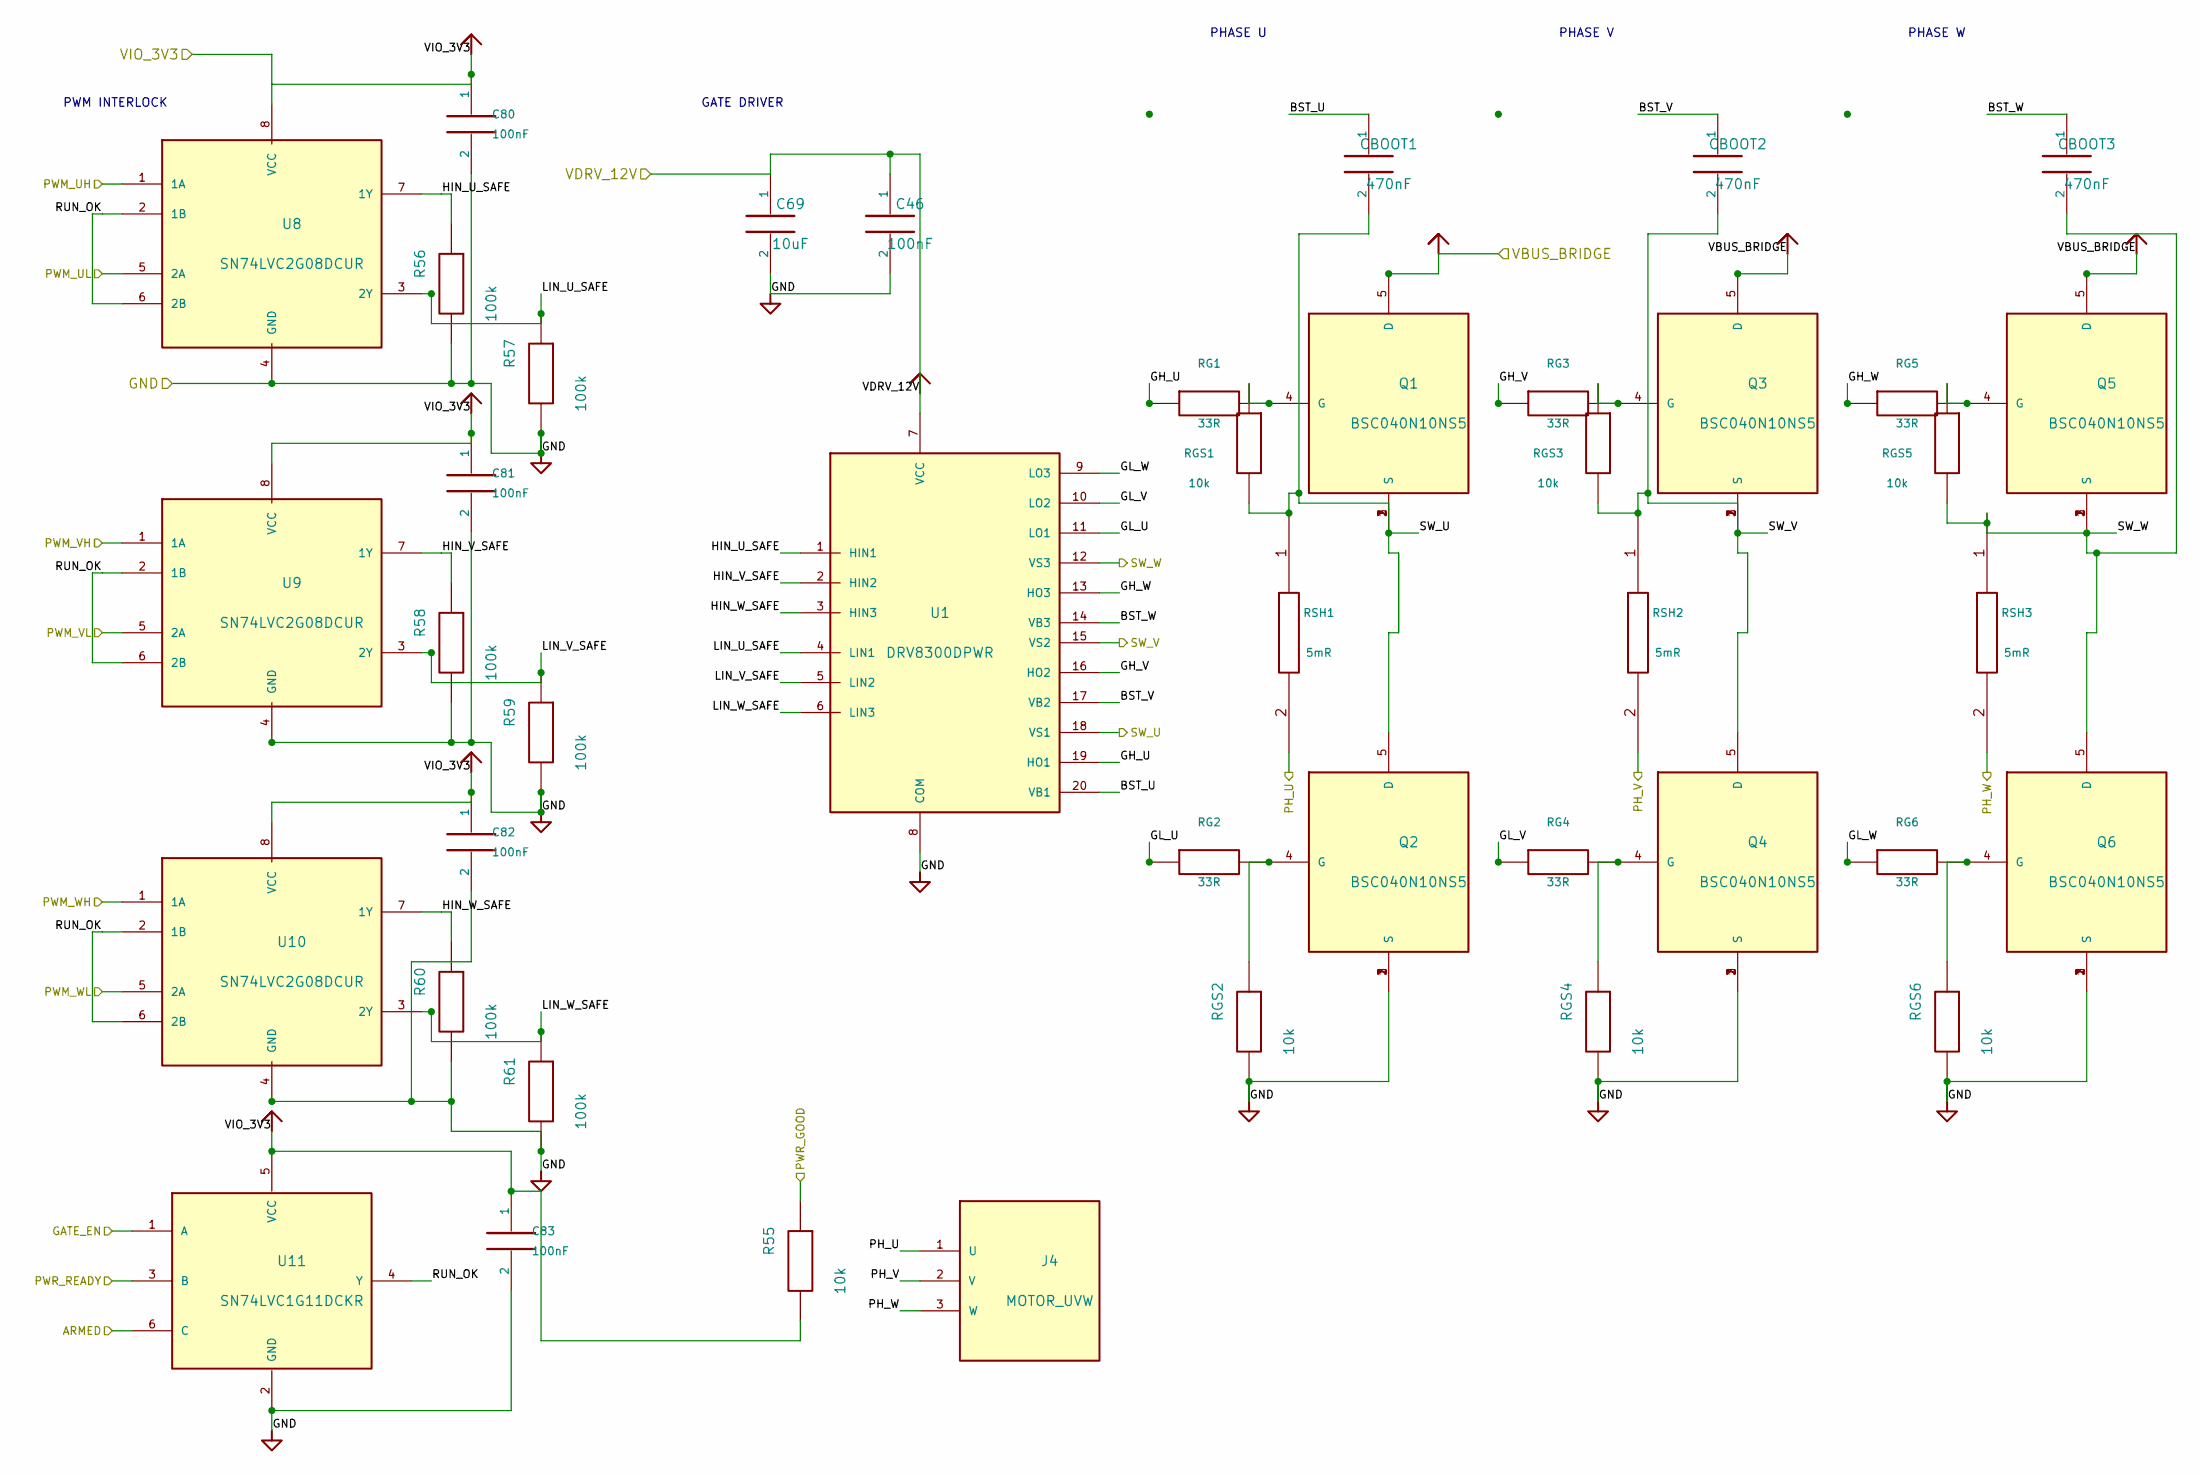
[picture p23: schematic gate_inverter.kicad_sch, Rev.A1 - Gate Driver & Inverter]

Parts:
C46, C80, C81, C82, C83: 100nF; C_0603_1608Metric; MPN 0603B104K500NT; LCSC C30926
C69: 10uF; C_1206_3216Metric; MPN CGA1206X7R106K250NT; LCSC C6119987
CBOOT1, CBOOT2, CBOOT3: 470nF; C_0805_2012Metric; MPN 0805B474K500NT; LCSC C49955
J4: MOTOR_UVW; KEFA_KF950_3_9.50mm; MPN KF950-9.5-3P; LCSC C475107
Q1, Q2, Q3, Q4, Q5, Q6: BSC040N10NS5; Infineon_PG-TDSON-8_6.15x5.15mm; MPN BSC040N10NS5; LCSC C534334
R55: 10k; R_0603_1608Metric; MPN ABD03K1002FT; LCSC C5139509
R56, R57, R58, R59, R60, R61: 100k; R_0603_1608Metric; MPN RS-03K1003FT; LCSC C115320
RG1, RG2, RG3, RG4, RG5, RG6: 33R; R_0603_1608Metric; MPN RS-03K33R0FT; LCSC C125766
RGS1, RGS2, RGS3, RGS4, RGS5, RGS6: 10k; R_0603_1608Metric; MPN ABD03K1002FT; LCSC C5139509
RSH1, RSH2, RSH3: 5mR; HoYLR2512_Kelvin; MPN HoYLR2512-3W-5mR-1%; LCSC C5375461
U1: DRV8300DPWR; TSSOP-20_4.4x6.5mm_P0.65mm; MPN DRV8300DPWR; LCSC C3036056
U8, U9, U10: SN74LVC2G08DCUR; TI_DCU0008A_VSSOP8_P0.5mm; MPN SN74LVC2G08DCUR; LCSC C91875
U11: SN74LVC1G11DCKR; SOT-363_SC-70-6; MPN SN74LVC1G11DCKR; LCSC C529281

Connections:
/ARMED: U11.6 (C); also elsewhere on the board
/GATE_EN: U11.1 (A); also elsewhere on the board
/Gate Driver / Inverter/BST_U: CBOOT1.1, U1.20 (VB1); also elsewhere on the board
/Gate Driver / Inverter/BST_V: CBOOT2.1, U1.17 (VB2); also elsewhere on the board
/Gate Driver / Inverter/BST_W: CBOOT3.1, U1.14 (VB3); also elsewhere on the board
/Gate Driver / Inverter/GH_U: RG1.1, U1.19 (HO1)
/Gate Driver / Inverter/GH_V: RG3.1, U1.16 (HO2)
/Gate Driver / Inverter/GH_W: RG5.1, U1.13 (HO3)
/Gate Driver / Inverter/GL_U: RG2.1, U1.11 (LO1)
/Gate Driver / Inverter/GL_V: RG4.1, U1.10 (LO2)
/Gate Driver / Inverter/GL_W: RG6.1, U1.9 (LO3)
/Gate Driver / Inverter/HIN_U_SAFE: R56.1, U1.1 (HIN1), U8.7 (1Y)
/Gate Driver / Inverter/HIN_V_SAFE: R58.1, U1.2 (HIN2), U9.7 (1Y)
/Gate Driver / Inverter/HIN_W_SAFE: R60.1, U1.3 (HIN3), U10.7 (1Y)
/Gate Driver / Inverter/LIN_U_SAFE: R57.1, U1.4 (LIN1), U8.3 (2Y)
/Gate Driver / Inverter/LIN_V_SAFE: R59.1, U1.5 (LIN2), U9.3 (2Y)
/Gate Driver / Inverter/LIN_W_SAFE: R61.1, U1.6 (LIN3), U10.3 (2Y)
/Gate Driver / Inverter/RUN_OK: U8.2 (1B), U8.6 (2B), U9.2 (1B), U9.6 (2B), U10.2 (1B), U10.6 (2B), U11.4 (Y)
/PH_U: J4.1 (U), RSH1.2, RSH1.4; also elsewhere on the board
/PH_V: J4.2 (V), RSH2.2, RSH2.4; also elsewhere on the board
/PH_W: J4.3 (W), RSH3.2, RSH3.4; also elsewhere on the board
/PWM_UH: U8.1 (1A); also elsewhere on the board
/PWM_UL: U8.5 (2A); also elsewhere on the board
/PWM_VH: U9.1 (1A); also elsewhere on the board
/PWM_VL: U9.5 (2A); also elsewhere on the board
/PWM_WH: U10.1 (1A); also elsewhere on the board
/PWM_WL: U10.5 (2A); also elsewhere on the board
/PWR_GOOD: R55.1; also elsewhere on the board
/PWR_READY: U11.3 (B); also elsewhere on the board
/SW_U: CBOOT1.2, Q1.1 (S), Q1.2 (S), Q1.3 (S), Q2.5 (D), RGS1.2, RSH1.1, RSH1.3, U1.18 (VS1); also elsewhere on the board
/SW_V: CBOOT2.2, Q3.1 (S), Q3.2 (S), Q3.3 (S), Q4.5 (D), RGS3.2, RSH2.1, RSH2.3, U1.15 (VS2); also elsewhere on the board
/SW_W: CBOOT3.2, Q5.1 (S), Q5.2 (S), Q5.3 (S), Q6.5 (D), RGS5.2, RSH3.1, RSH3.3, U1.12 (VS3); also elsewhere on the board
/VBUS_PROT: Q1.5 (D), Q3.5 (D), Q5.5 (D); also elsewhere on the board
/VDRV_12V: C46.1, C69.1, U1.7 (VCC); also elsewhere on the board
/VIO_3V3: C80.1, C81.1, C82.1, C83.1, R55.2, U8.8 (VCC), U9.8 (VCC), U10.8 (VCC), U11.5 (VCC); also elsewhere on the board
unnamed: Q1.4 (G), RG1.2, RGS1.1
unnamed: Q2.4 (G), RG2.2, RGS2.1
unnamed: Q3.4 (G), RG3.2, RGS3.1
unnamed: Q4.4 (G), RG4.2, RGS4.1
unnamed: Q5.4 (G), RG5.2, RGS5.1
unnamed: Q6.4 (G), RG6.2, RGS6.1

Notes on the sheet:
PWM INTERLOCK
GATE DRIVER
PHASE U
PHASE V
PHASE W

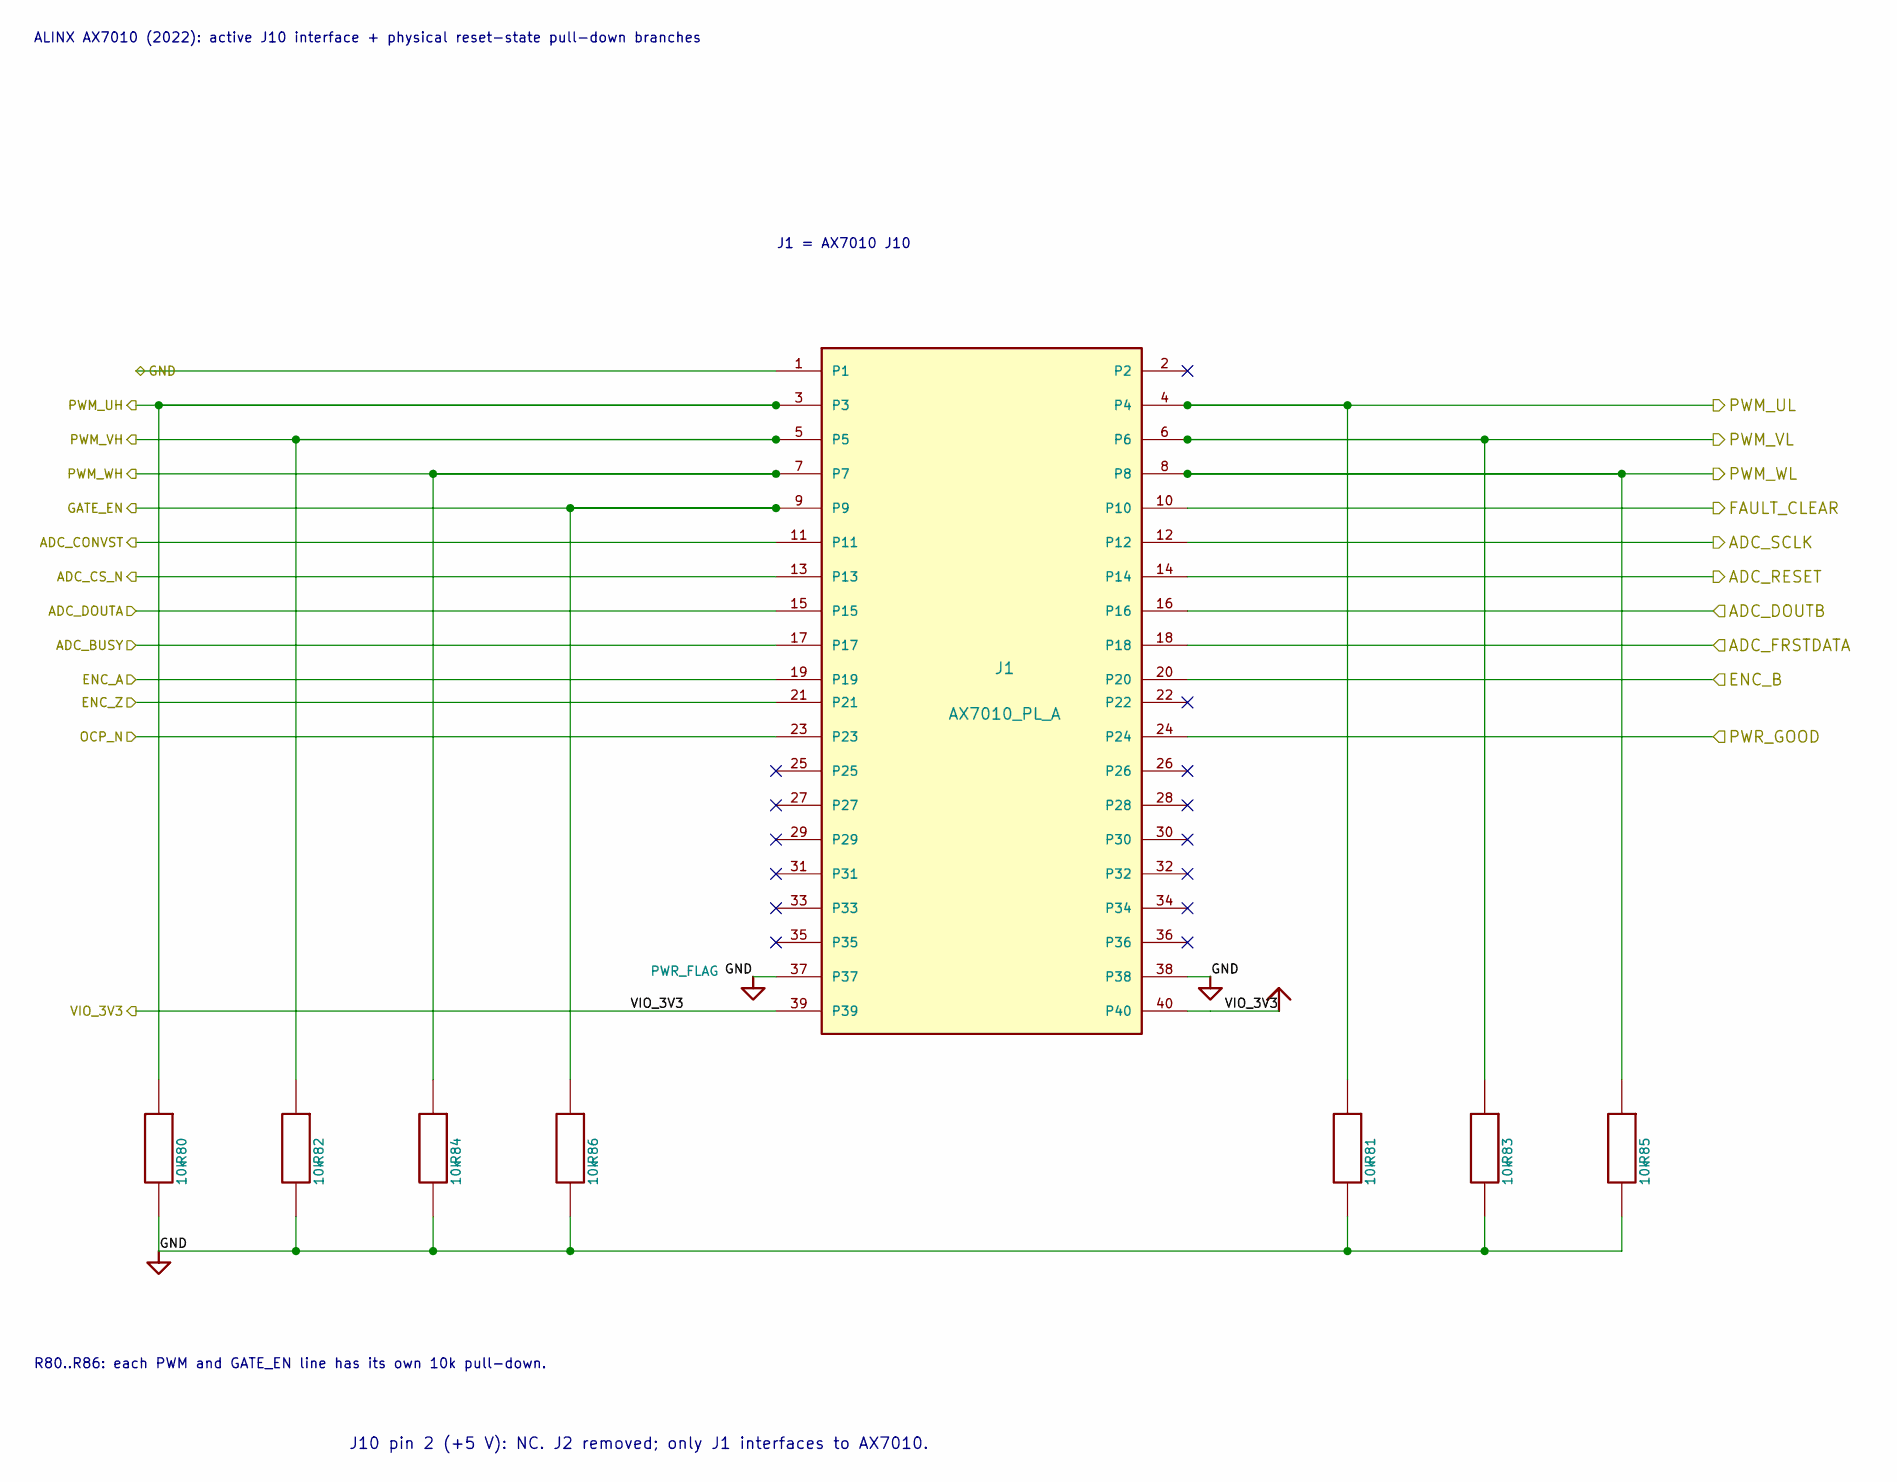
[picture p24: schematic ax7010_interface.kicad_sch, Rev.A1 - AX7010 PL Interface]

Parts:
J1: AX7010_PL_A; JILN_3210_2x20_P2.54mm_D1.02; MPN 321040SG0ABK00A01; LCSC C601944
R80, R81, R82, R83, R84, R85, R86: 10k; R_0603_1608Metric; MPN ABD03K1002FT; LCSC C5139509

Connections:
/ADC_BUSY: J1.17; also elsewhere on the board
/ADC_CONVST: J1.11; also elsewhere on the board
/ADC_CS_N: J1.13; also elsewhere on the board
/ADC_DOUTA: J1.15; also elsewhere on the board
/ADC_DOUTB: J1.16; also elsewhere on the board
/ADC_FRSTDATA: J1.18; also elsewhere on the board
/ADC_RESET: J1.14; also elsewhere on the board
/ADC_SCLK: J1.12; also elsewhere on the board
/ENC_A: J1.19; also elsewhere on the board
/ENC_B: J1.20; also elsewhere on the board
/ENC_Z: J1.21; also elsewhere on the board
/FAULT_CLEAR: J1.10; also elsewhere on the board
/GATE_EN: J1.9, R86.1; also elsewhere on the board
/OCP_N: J1.23; also elsewhere on the board
/PWM_UH: J1.3, R80.1; also elsewhere on the board
/PWM_UL: J1.4, R81.1; also elsewhere on the board
/PWM_VH: J1.5, R82.1; also elsewhere on the board
/PWM_VL: J1.6, R83.1; also elsewhere on the board
/PWM_WH: J1.7, R84.1; also elsewhere on the board
/PWM_WL: J1.8, R85.1; also elsewhere on the board
/PWR_GOOD: J1.24; also elsewhere on the board
/VIO_3V3: J1.39, J1.40; also elsewhere on the board

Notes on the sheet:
ALINX AX7010 (2022): active J10 interface + physical reset-state pull-down branches
J1 = AX7010 J10
R80..R86: each PWM and GATE_EN line has its own 10k pull-down.
J10 pin 2 (+5 V): NC. J2 removed; only J1 interfaces to AX7010.

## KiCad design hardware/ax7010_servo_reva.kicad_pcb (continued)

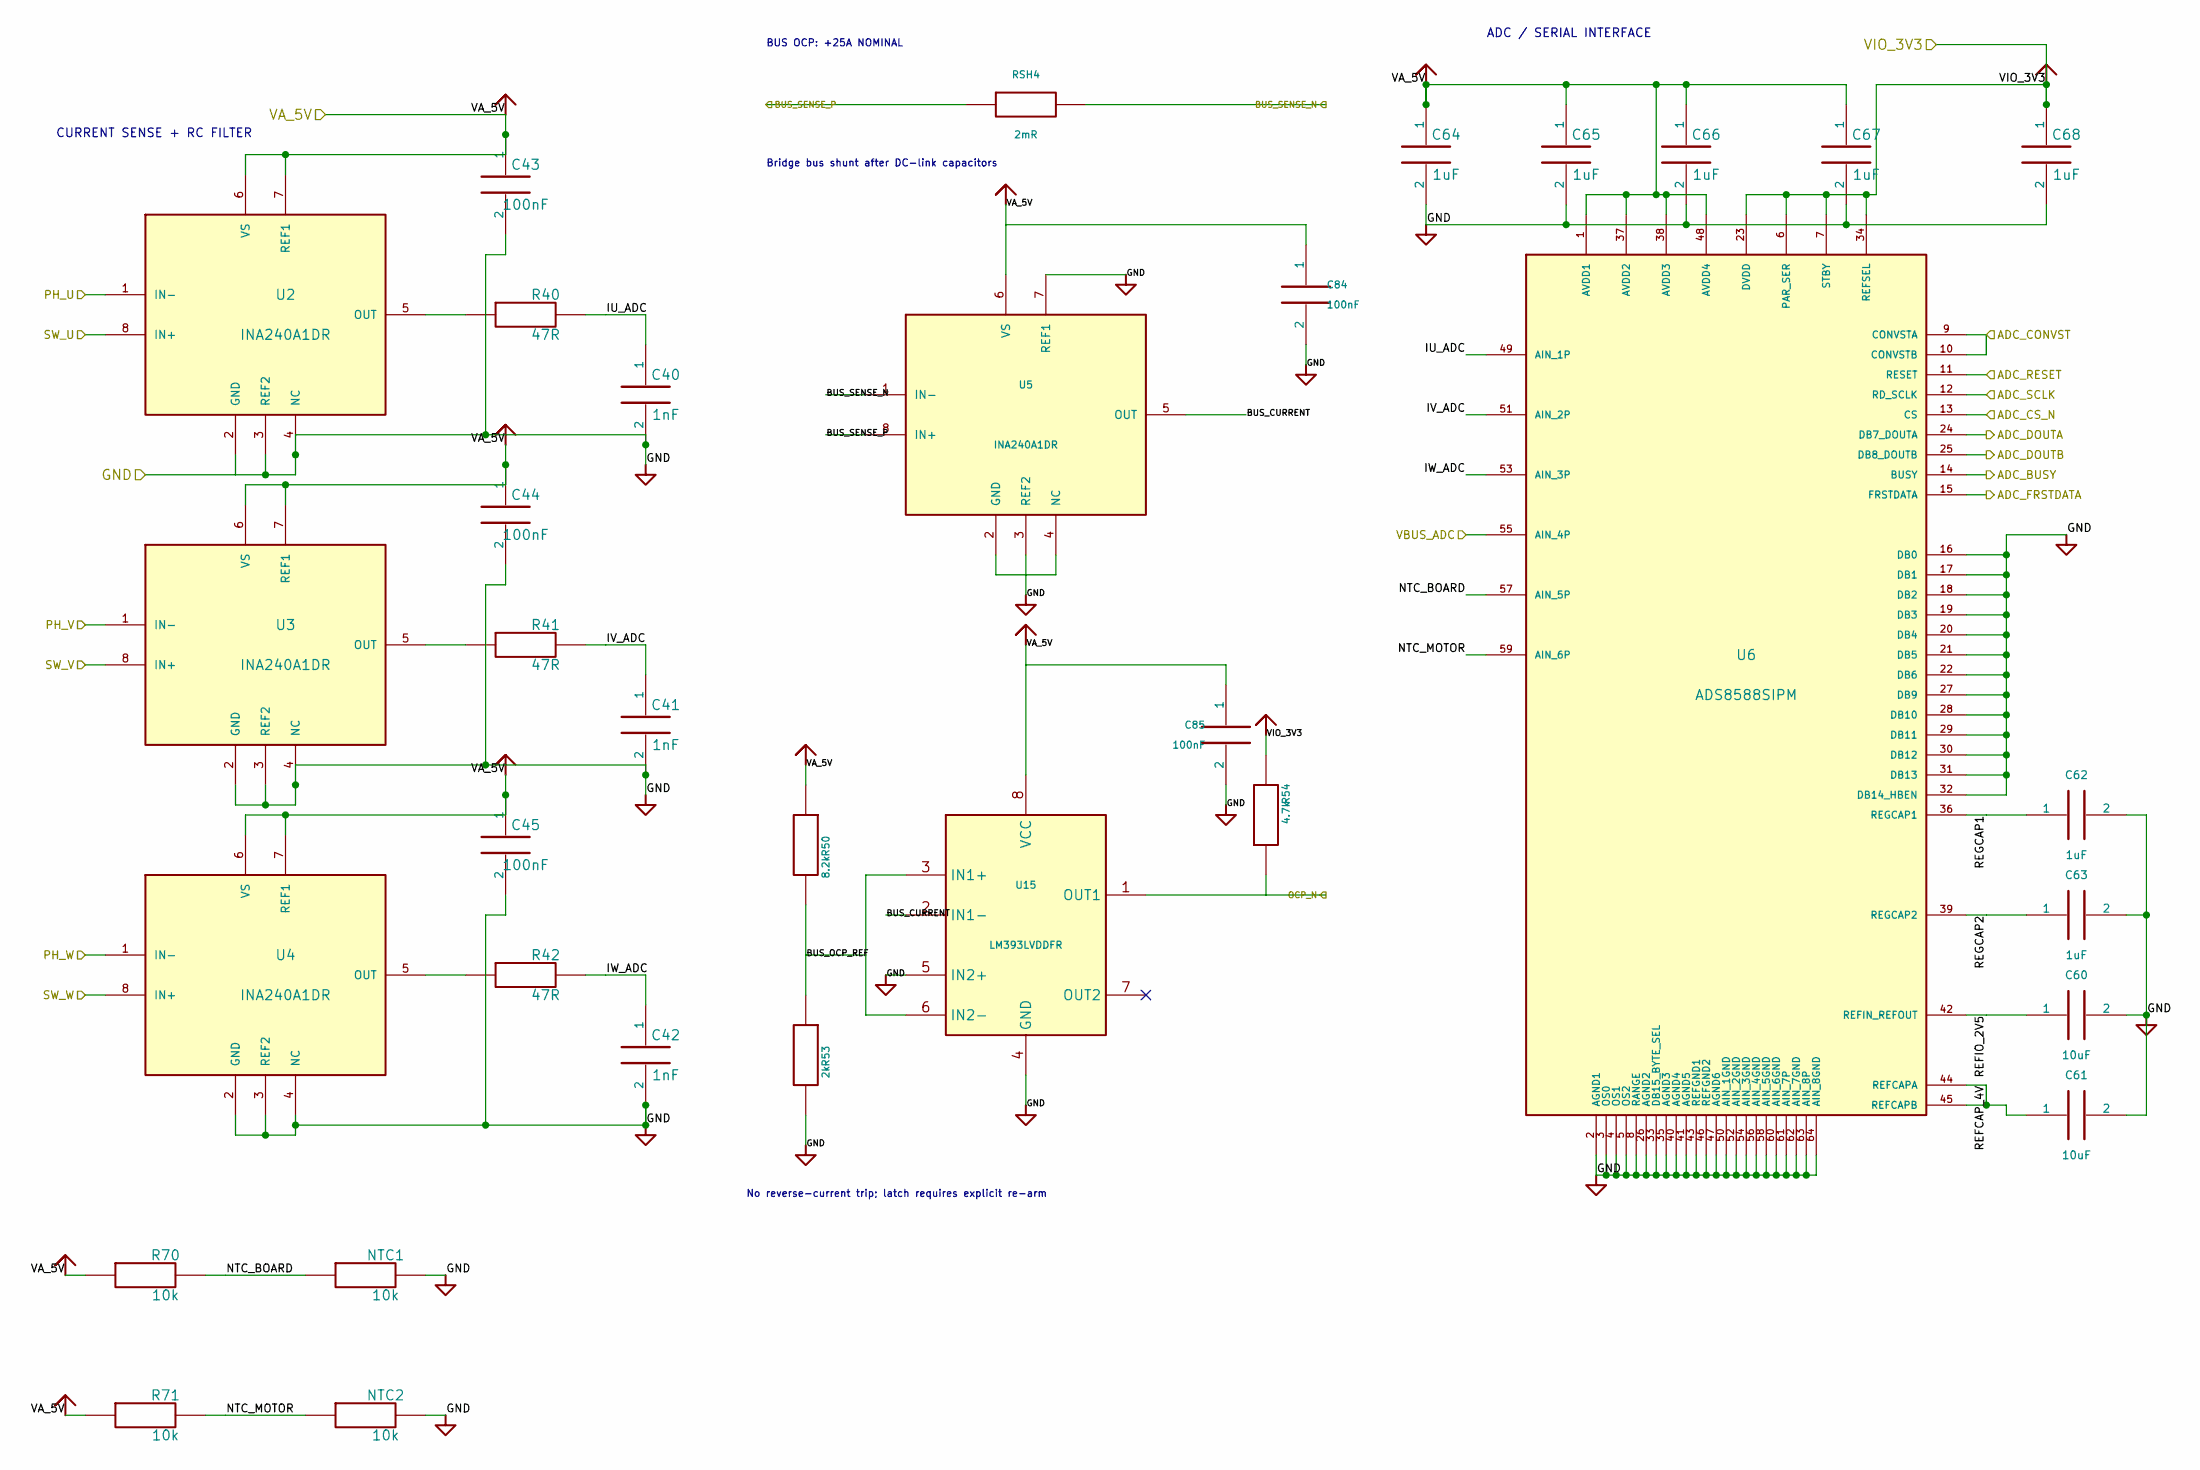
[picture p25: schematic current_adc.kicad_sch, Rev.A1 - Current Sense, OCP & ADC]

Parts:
C40, C41, C42: 1nF; C_0603_1608Metric; MPN 0603CG102J101NT; LCSC C88489
C43, C44, C45, C84, C85: 100nF; C_0603_1608Metric; MPN 0603B104K500NT; LCSC C30926
C60, C61: 10uF; C_0805_2012Metric; MPN HGC0805R7106K250NSLJ; LCSC C33546010
C62, C63, C64, C65, C66, C67, C68: 1uF; C_0603_1608Metric; MPN 0603B105K250NT; LCSC C59302
NTC1, NTC2: 10k; NTC_0603_Shiheng_KUU; MPN CMFA 103F3950; LCSC C2889049
R40, R41, R42: 47R; R_0603_1608Metric; MPN RS-03K47R0FT; LCSC C140087
R50: 8.2k; R_0603_1608Metric; Tolerance 0.1%; MPN PTFR0603B8K20P9; LCSC C351624
R53: 2k; R_0603_1608Metric; Tolerance 0.1%; MPN TD03G2001BT; LCSC C666953
R54: 4.7k; R_0603_1608Metric; MPN RS-03K4701FT; LCSC C116693
R70, R71: 10k; R_0603_1608Metric; MPN TD03G1002BT; LCSC C667034
RSH4: 2mR; HoYLR2512_Kelvin; MPN HoYLR2512-3W-2mR-1%; LCSC C5375458
U2, U3, U4, U5: INA240A1DR; TI_D0008A_SOIC8_P1.27mm; MPN INA240A1DR; LCSC C2060769
U6: ADS8588SIPM; LQFP-64_10x10mm_P0.5mm; MPN ADS8588SIPM; LCSC C1543171
U15: LM393LVDDFR; TI_DDF0008A; MPN LM393LVDDFR; LCSC C5213974

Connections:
/ADC_BUSY: U6.14 (BUSY); also elsewhere on the board
/ADC_CONVST: U6.9 (CONVSTA), U6.10 (CONVSTB); also elsewhere on the board
/ADC_CS_N: U6.13 (CS); also elsewhere on the board
/ADC_DOUTA: U6.24 (DB7_DOUTA); also elsewhere on the board
/ADC_DOUTB: U6.25 (DB8_DOUTB); also elsewhere on the board
/ADC_FRSTDATA: U6.15 (FRSTDATA); also elsewhere on the board
/ADC_RESET: U6.11 (RESET); also elsewhere on the board
/ADC_SCLK: U6.12 (RD_SCLK); also elsewhere on the board
/Current Sense / OCP / ADC/NTC_BOARD: NTC1.1, R70.2, U6.57 (AIN_5P)
/Current Sense / OCP / ADC/NTC_MOTOR: NTC2.1, R71.2, U6.59 (AIN_6P)
/Current Sense / OCP / ADC/REFCAP_4V: C61.1, U6.44 (REFCAPA), U6.45 (REFCAPB)
/Current Sense / OCP / ADC/REFIO_2V5: C60.1, U6.42 (REFIN_REFOUT)
/Current Sense / OCP / ADC/REGCAP1: C62.1, U6.36 (REGCAP1)
/Current Sense / OCP / ADC/REGCAP2: C63.1, U6.39 (REGCAP2)
/OCP_N: R54.1, U5.5 (OUT), U15.1 (OUT1), U15.2 (IN1-), U15.14; also elsewhere on the board
/PH_U: U2.1 (IN-); also elsewhere on the board
/PH_V: U3.1 (IN-); also elsewhere on the board
/PH_W: U4.1 (IN-); also elsewhere on the board
/SW_U: U2.8 (IN+); also elsewhere on the board
/SW_V: U3.8 (IN+); also elsewhere on the board
/SW_W: U4.8 (IN+); also elsewhere on the board
/VBUS_ADC: U6.55 (AIN_4P); also elsewhere on the board
/VIO_3V3: C68.1, R54.2, U6.6 (PAR_SER), U6.7 (STBY), U6.23 (DVDD), U6.34 (REFSEL); also elsewhere on the board
unnamed: R40.1, U2.5 (OUT)
unnamed: R41.1, U3.5 (OUT)
unnamed: R42.1, U4.5 (OUT)

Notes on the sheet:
CURRENT SENSE + RC FILTER
ADC / SERIAL INTERFACE
BUS OCP: +25A NOMINAL
No reverse-current trip; latch requires explicit re-arm
Bridge bus shunt after DC-link capacitors

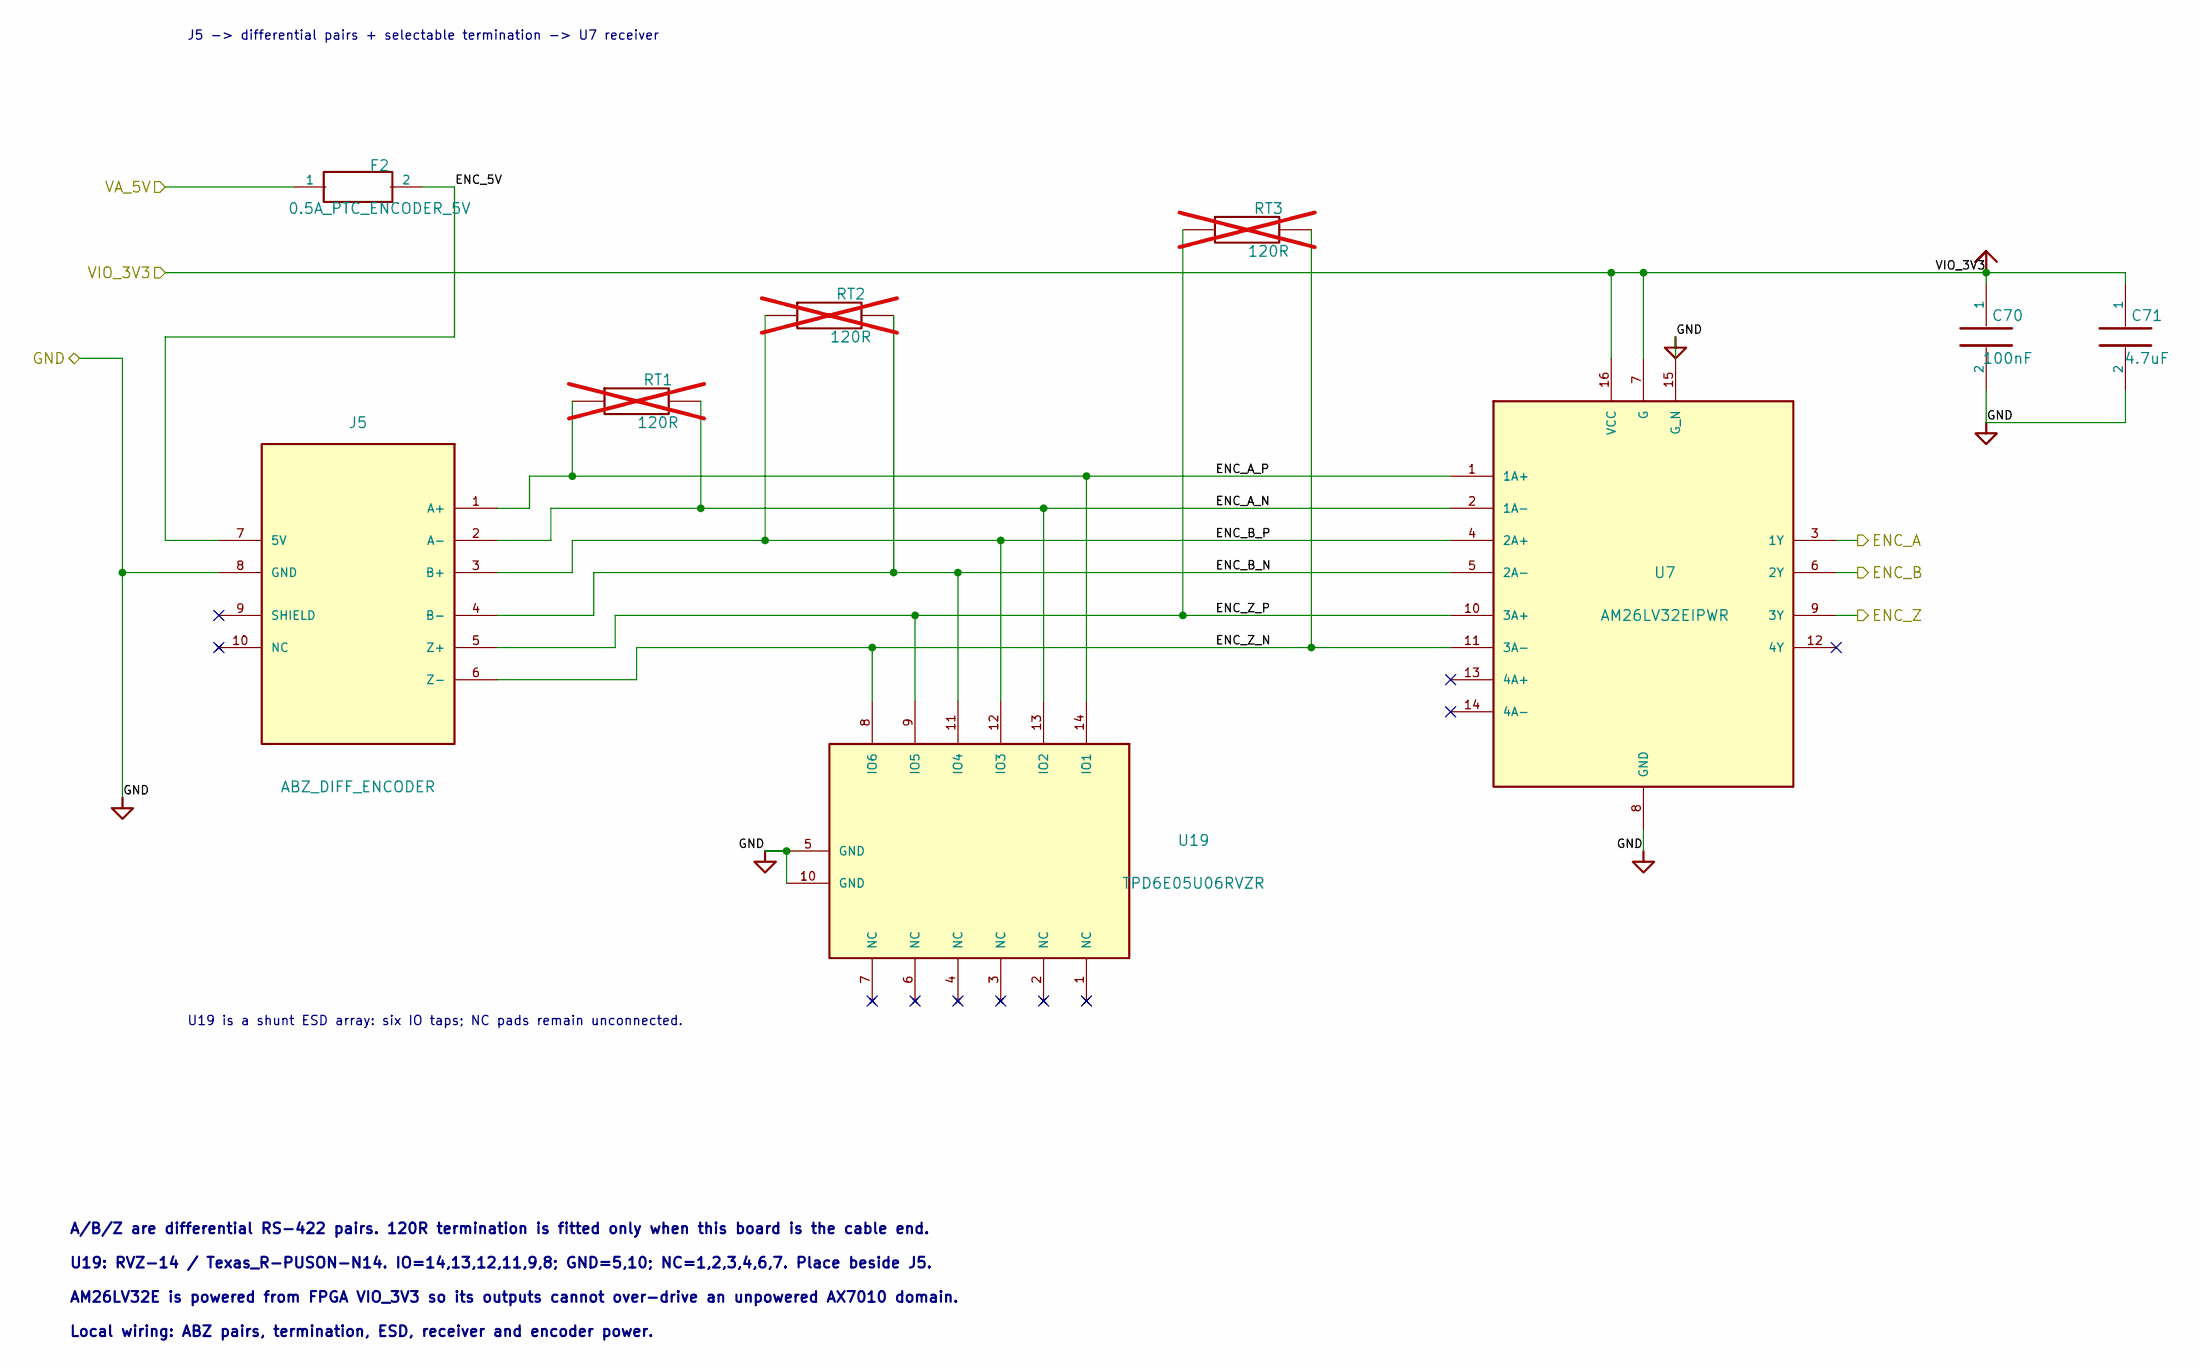
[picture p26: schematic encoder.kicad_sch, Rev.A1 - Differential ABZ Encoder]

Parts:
C70: 100nF; C_0603_1608Metric; MPN 0603B104K500NT; LCSC C30926
C71: 4.7uF; C_0805_2012Metric; MPN CGA0805X7R475K250MT; LCSC C6119942
F2: 0.5A_PTC_ENCODER_5V; Fuse_1812_4532Metric; MPN ASMD1812-050; LCSC C135358
J5: ABZ_DIFF_ENCODER; JILN_3210_2x05_P2.54mm_D1.02; MPN 321010SG0ABK00A01; LCSC C429962
RT1, RT2, RT3: 120R; R_0603_1608Metric; not fitted
U7: AM26LV32EIPWR; TSSOP-16_4.4x5mm_P0.65mm; MPN AM26LV32EIPWR; LCSC C404024
U19: TPD6E05U06RVZR; Texas_R-PUSON-N14; MPN TPD6E05U06RVZR; LCSC C962978

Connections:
/Differential ABZ Encoder/ENC_5V: F2.2, J5.7 (5V)
/Differential ABZ Encoder/ENC_A_N: J5.2 (A-), RT1.2, U7.2 (1A-), U19.13 (IO2)
/Differential ABZ Encoder/ENC_A_P: J5.1 (A+), RT1.1, U7.1 (1A+), U19.14 (IO1)
/Differential ABZ Encoder/ENC_B_N: J5.4 (B-), RT2.2, U7.5 (2A-), U19.11 (IO4)
/Differential ABZ Encoder/ENC_B_P: J5.3 (B+), RT2.1, U7.4 (2A+), U19.12 (IO3)
/Differential ABZ Encoder/ENC_Z_N: J5.6 (Z-), RT3.2, U7.11 (3A-), U19.8 (IO6)
/Differential ABZ Encoder/ENC_Z_P: J5.5 (Z+), RT3.1, U7.10 (3A+), U19.9 (IO5)
/ENC_A: U7.3 (1Y); also elsewhere on the board
/ENC_B: U7.6 (2Y); also elsewhere on the board
/ENC_Z: U7.9 (3Y); also elsewhere on the board
/VIO_3V3: C70.1, C71.1, U7.7 (G), U7.16 (VCC); also elsewhere on the board

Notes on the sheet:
Local wiring: ABZ pairs, termination, ESD, receiver and encoder power.
A/B/Z are differential RS-422 pairs. 120R termination is fitted only when this board is the cable end.
U19: RVZ-14 / Texas_R-PUSON-N14. IO=14,13,12,11,9,8; GND=5,10; NC=1,2,3,4,6,7. Place beside J5.
AM26LV32E is powered from FPGA VIO_3V3 so its outputs cannot over-drive an unpowered AX7010 domain.
J5 -> differential pairs + selectable termination -> U7 receiver
U19 is a shunt ESD array: six IO taps; NC pads remain unconnected.

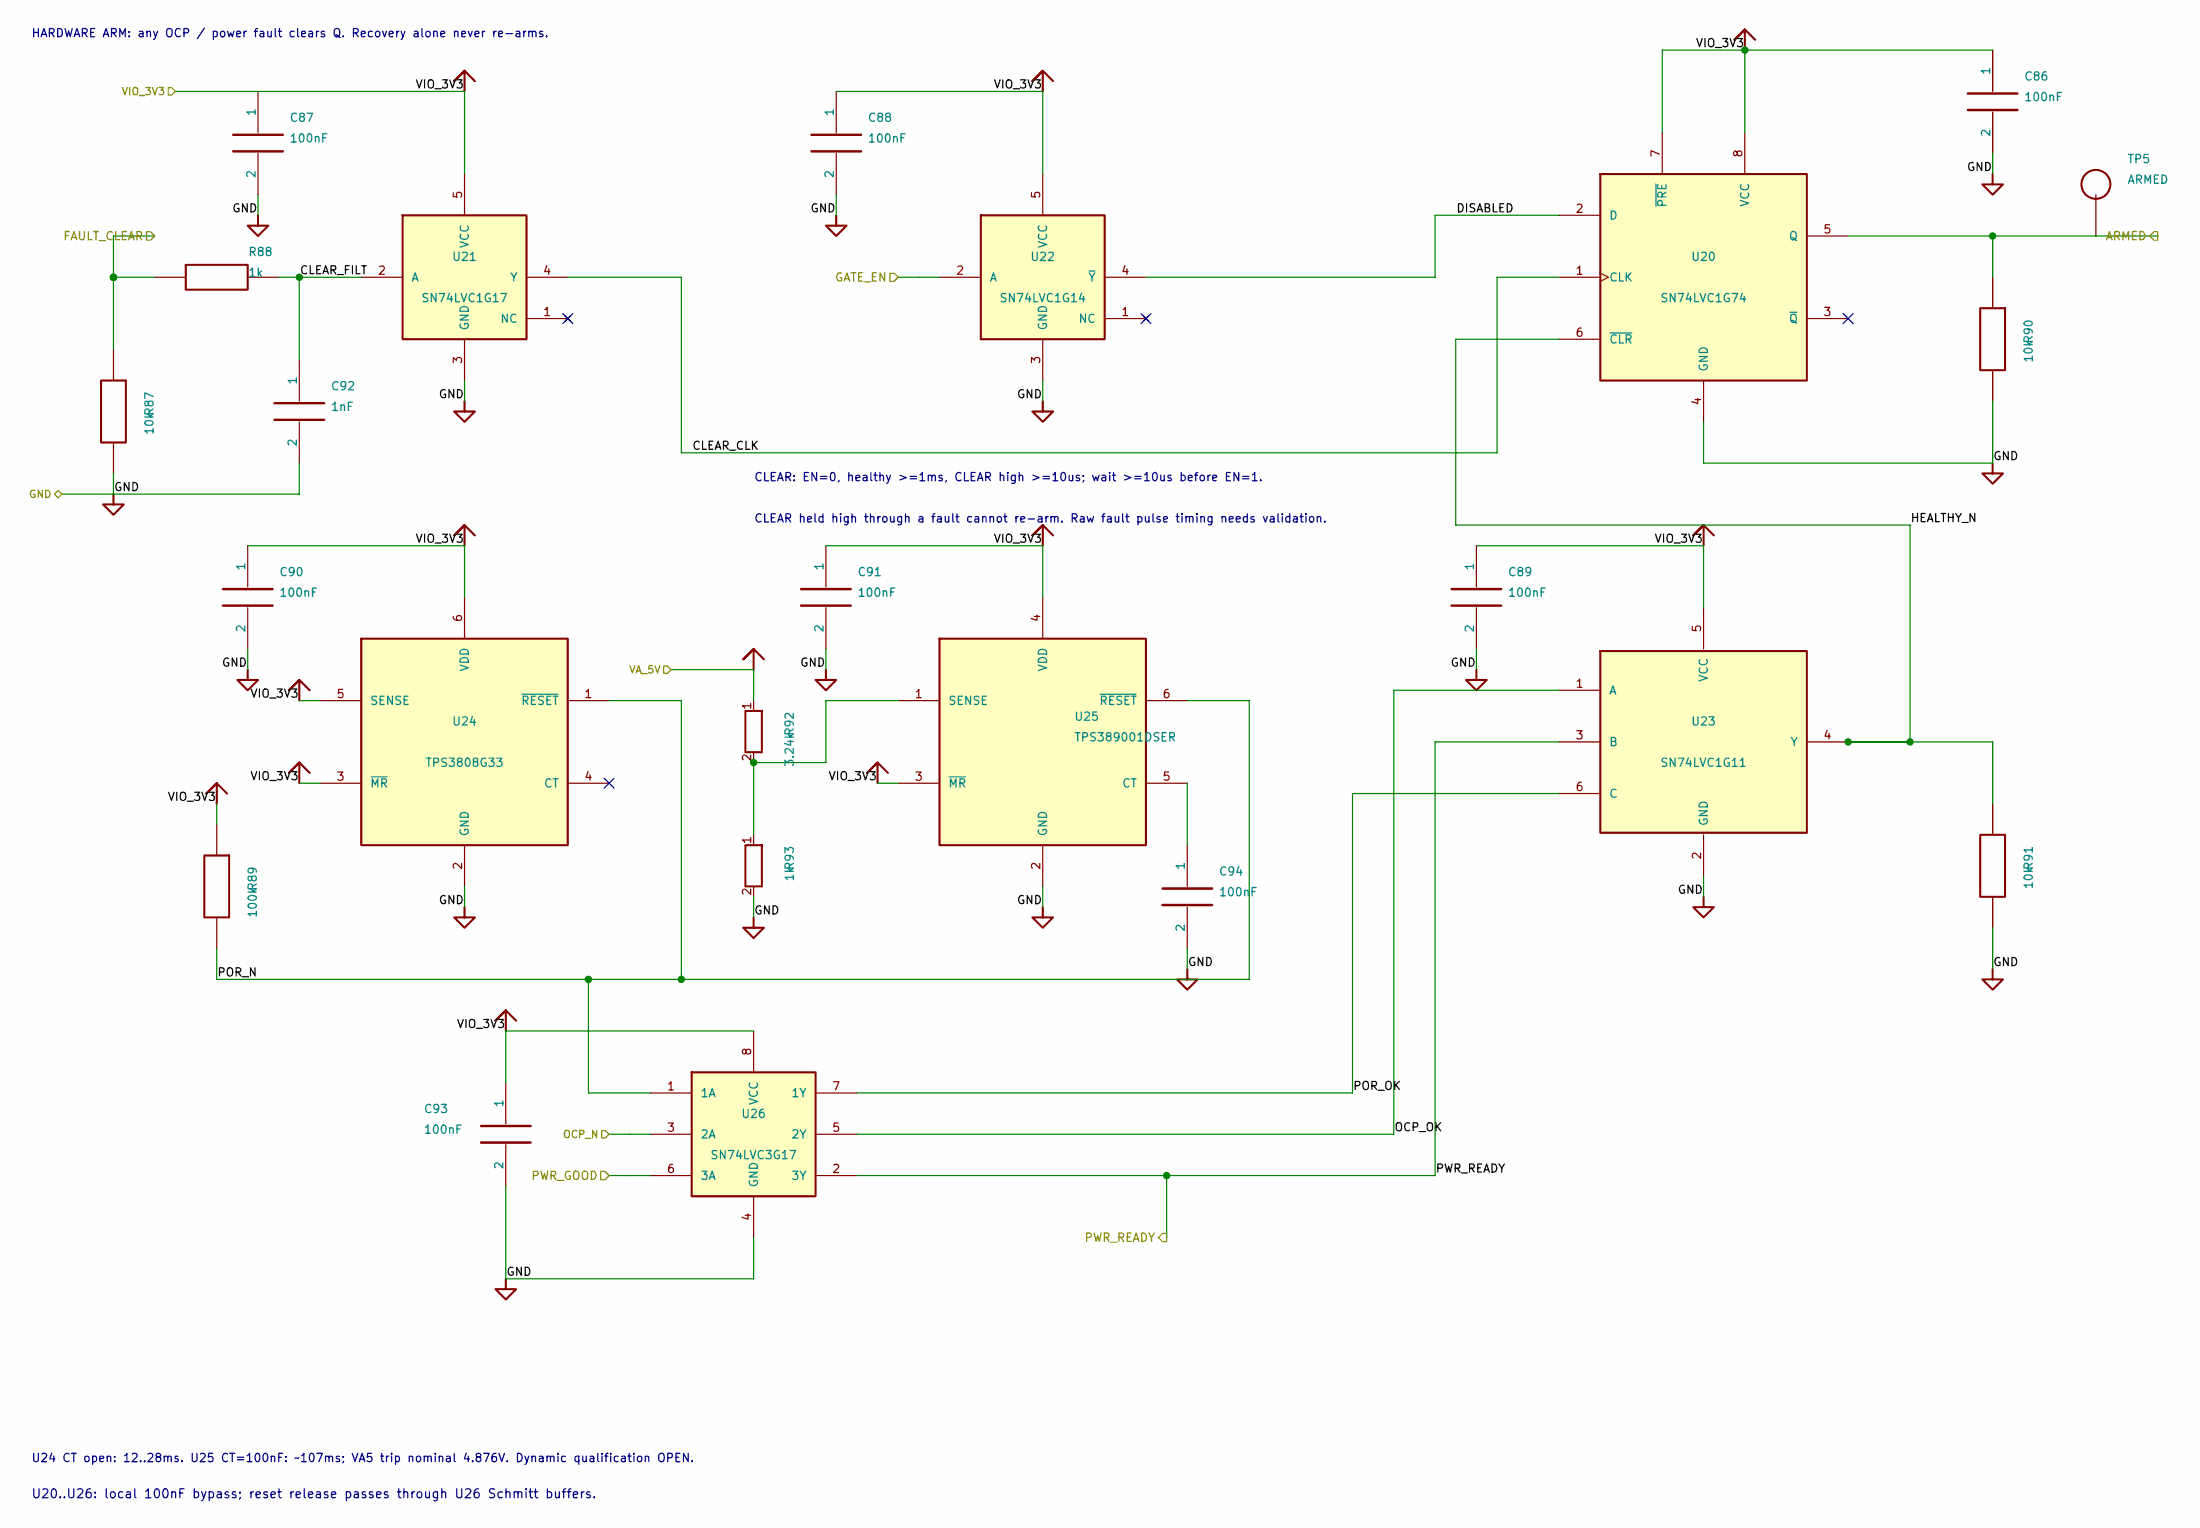
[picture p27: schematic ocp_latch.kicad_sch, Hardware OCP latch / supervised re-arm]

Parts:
C86, C87, C88, C89, C90, C91, C93: 100nF; C_0603_1608Metric; MPN 0603B104K500NT; LCSC C30926
C92: 1nF; C_0603_1608Metric; MPN 0603CG102J101NT; LCSC C88489
C94: 100nF; C_1206_3216Metric; MPN GRT31C5C1H104FA02L; LCSC C3839854
R87, R90, R91: 10k; R_0603_1608Metric; MPN ABD03K1002FT; LCSC C5139509
R88: 1k; R_0603_1608Metric; MPN ABD03K1001FT; LCSC C5125843
R89: 100k; R_0603_1608Metric; MPN RS-03K1003FT; LCSC C115320
R92: 3.24k; R_0603_1608Metric; Tolerance 0.1%; MPN TD03G3241BT; LCSC C666977
R93: 1k; R_0603_1608Metric; Tolerance 0.05%; MPN PTFR0603Q1K00N9; LCSC C23067434
TP5: ARMED; TestPoint_Pad_D1.5mm
U20: SN74LVC1G74; TI_DCU0008A_VSSOP8_P0.5mm; MPN SN74LVC1G74DCUR; LCSC C70285
U21: SN74LVC1G17; SOT-23-5; MPN SN74LVC1G17DBVR; LCSC C7836
U22: SN74LVC1G14; SOT-23-5; MPN SN74LVC1G14DBVR; LCSC C7835
U23: SN74LVC1G11; SOT-363_SC-70-6; MPN SN74LVC1G11DCKR; LCSC C529281
U24: TPS3808G33; SOT-23-6; MPN TPS3808G33DBVR; LCSC C43698
U25: TPS389001DSER; Texas_DSE0006A_WSON-6_1.5x1.5mm; MPN TPS389001DSER; LCSC C1509297
U26: SN74LVC3G17; TI_DCU0008A_VSSOP8_P0.5mm; MPN SN74LVC3G17DCUR; LCSC C68245

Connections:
/ARMED: R90.1, TP5.1, U20.5 (Q); also elsewhere on the board
/FAULT_CLEAR: R87.1, R88.1; also elsewhere on the board
/GATE_EN: U22.2 (A); also elsewhere on the board
/OCP hardware latch/CLEAR_CLK: U20.1 (CLK), U21.4 (Y)
/OCP hardware latch/CLEAR_FILT: C92.1, R88.2, U21.2 (A)
/OCP hardware latch/DISABLED: U20.2 (D), U22.4 (~Y)
/OCP hardware latch/HEALTHY_N: R91.1, U20.6 (~CLR), U23.4 (Y)
/OCP hardware latch/OCP_OK: U23.1 (A), U26.5 (2Y)
/OCP hardware latch/POR_N: R89.2, U24.1 (~RESET), U25.6 (~RESET), U26.1 (1A)
/OCP hardware latch/POR_OK: U23.6 (C), U26.7 (1Y)
/OCP_N: U26.3 (2A); also elsewhere on the board
/PWR_GOOD: U26.6 (3A); also elsewhere on the board
/PWR_READY: U23.3 (B), U26.2 (3Y); also elsewhere on the board
/VIO_3V3: C86.1, C87.1, C88.1, C89.1, C90.1, C91.1, C93.1, R89.1, U20.7 (~PRE), U20.8 (VCC), U21.5 (VCC), U22.5 (VCC), U23.5 (VCC), U24.3 (~MR), U24.5 (SENSE), U24.6 (VDD), U25.3 (~MR), U25.4 (VDD), U26.8 (VCC); also elsewhere on the board
unnamed: C94.1, U25.5 (CT)
unnamed: R92.2, R93.1, U25.1 (SENSE)

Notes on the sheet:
HARDWARE ARM: any OCP / power fault clears Q. Recovery alone never re-arms.
CLEAR: EN=0, healthy >=1ms, CLEAR high >=10us; wait >=10us before EN=1.
U24 CT open: 12..28ms. U25 CT=100nF: ~107ms; VA5 trip nominal 4.876V. Dynamic qualification OPEN.
CLEAR held high through a fault cannot re-arm. Raw fault pulse timing needs validation.
U20..U26: local 100nF bypass; reset release passes through U26 Schmitt buffers.

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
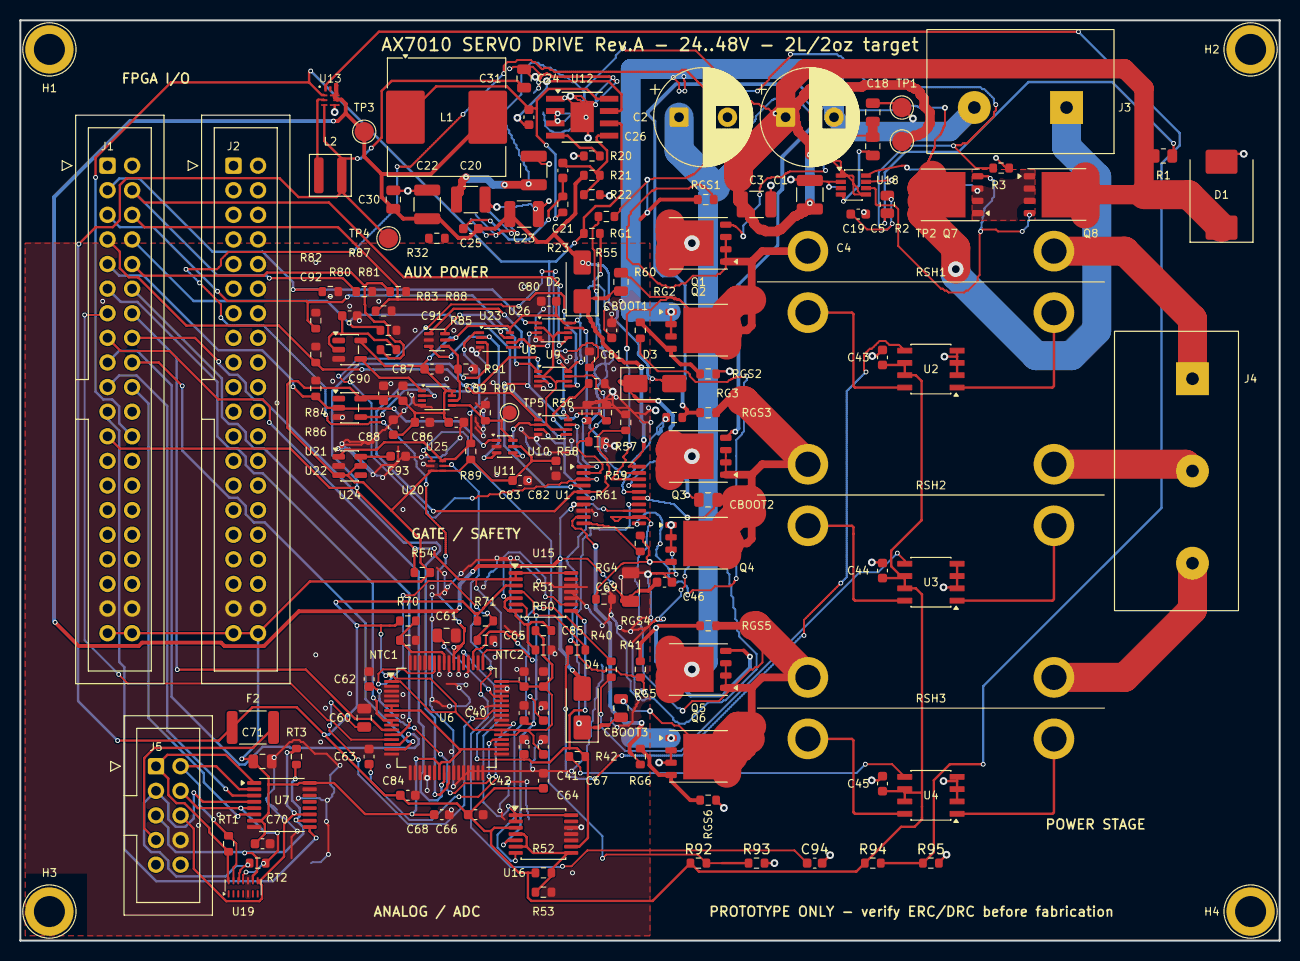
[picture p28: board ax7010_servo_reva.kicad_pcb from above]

Board: 2 copper layers, 130.0 x 95.0 mm, 166 parts (0 on the bottom side), 99 nets.

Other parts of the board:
D2, D3, D4: ES1J; D_SMA
H1, H2, H3, H4: M3_HOLE; MountingHole_M3_3.2mm_PTH_Pad5mm
J2: AX7010_PL_B; IDC-Header_2x20_P2.54mm_Vertical
R51, R52: 160k; R_0603_1608Metric
U16: LM339LVPWR; TSSOP-14_4.4x5mm_P0.65mm

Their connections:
/Gate Driver / Inverter/BST_U: D2.1; also elsewhere on the board
/Gate Driver / Inverter/BST_V: D3.1; also elsewhere on the board
/Gate Driver / Inverter/BST_W: D4.1; also elsewhere on the board
/OCP_N: U16.1, U16.2, U16.14; also elsewhere on the board
/VDRV_12V: D2.2, D3.2, D4.2; also elsewhere on the board
/VIO_3V3: J2.39, J2.40; also elsewhere on the board

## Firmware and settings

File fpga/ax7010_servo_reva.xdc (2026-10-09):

# AX7010 Servo Drive Rev.A
# Confirmed user hardware: AX7010 2022, active PL_A=J10. PL_B=J11 optional.
# Pin mapping checked against manufacturer schematic sheets 5/15; no pin changes.
# All user PL I/O here is 3.3 V LVCMOS.

# PL_A / J10
set_property PACKAGE_PIN W19 [get_ports PWM_UH];        set_property IOSTANDARD LVCMOS33 [get_ports PWM_UH]
set_property PACKAGE_PIN W18 [get_ports PWM_UL];        set_property IOSTANDARD LVCMOS33 [get_ports PWM_UL]
set_property PACKAGE_PIN R14 [get_ports PWM_VH];        set_property IOSTANDARD LVCMOS33 [get_ports PWM_VH]
set_property PACKAGE_PIN P14 [get_ports PWM_VL];        set_property IOSTANDARD LVCMOS33 [get_ports PWM_VL]
set_property PACKAGE_PIN Y17 [get_ports PWM_WH];        set_property IOSTANDARD LVCMOS33 [get_ports PWM_WH]
set_property PACKAGE_PIN Y16 [get_ports PWM_WL];        set_property IOSTANDARD LVCMOS33 [get_ports PWM_WL]
set_property PACKAGE_PIN W15 [get_ports GATE_EN];       set_property IOSTANDARD LVCMOS33 [get_ports GATE_EN]
set_property PACKAGE_PIN V15 [get_ports FAULT_CLEAR];   set_property IOSTANDARD LVCMOS33 [get_ports FAULT_CLEAR]
set_property PACKAGE_PIN Y14 [get_ports ADC_CONVST];    set_property IOSTANDARD LVCMOS33 [get_ports ADC_CONVST]
set_property PACKAGE_PIN W14 [get_ports ADC_SCLK];      set_property IOSTANDARD LVCMOS33 [get_ports ADC_SCLK]
set_property PACKAGE_PIN P18 [get_ports ADC_CS_N];      set_property IOSTANDARD LVCMOS33 [get_ports ADC_CS_N]
set_property PACKAGE_PIN N17 [get_ports ADC_RESET];     set_property IOSTANDARD LVCMOS33 [get_ports ADC_RESET]
set_property PACKAGE_PIN U15 [get_ports ADC_DOUTA];     set_property IOSTANDARD LVCMOS33 [get_ports ADC_DOUTA]
set_property PACKAGE_PIN U14 [get_ports ADC_DOUTB];     set_property IOSTANDARD LVCMOS33 [get_ports ADC_DOUTB]
set_property PACKAGE_PIN P16 [get_ports ADC_BUSY];      set_property IOSTANDARD LVCMOS33 [get_ports ADC_BUSY]
set_property PACKAGE_PIN P15 [get_ports ADC_FRSTDATA];  set_property IOSTANDARD LVCMOS33 [get_ports ADC_FRSTDATA]
set_property PACKAGE_PIN U17 [get_ports ENC_A];         set_property IOSTANDARD LVCMOS33 [get_ports ENC_A]
set_property PACKAGE_PIN T16 [get_ports ENC_B];         set_property IOSTANDARD LVCMOS33 [get_ports ENC_B]
set_property PACKAGE_PIN V18 [get_ports ENC_Z];         set_property IOSTANDARD LVCMOS33 [get_ports ENC_Z]
set_property PACKAGE_PIN V17 [get_ports ENC_FAULT_N];   set_property IOSTANDARD LVCMOS33 [get_ports ENC_FAULT_N]
set_property PACKAGE_PIN T15 [get_ports OCP_N];         set_property IOSTANDARD LVCMOS33 [get_ports OCP_N]
set_property PACKAGE_PIN T14 [get_ports PWR_GOOD];      set_property IOSTANDARD LVCMOS33 [get_ports PWR_GOOD]
set_property PACKAGE_PIN V13 [get_ports AUX_IN0];       set_property IOSTANDARD LVCMOS33 [get_ports AUX_IN0]
set_property PACKAGE_PIN U13 [get_ports AUX_IN1];       set_property IOSTANDARD LVCMOS33 [get_ports AUX_IN1]
set_property PACKAGE_PIN W13 [get_ports AUX_OUT0];      set_property IOSTANDARD LVCMOS33 [get_ports AUX_OUT0]
set_property PACKAGE_PIN V12 [get_ports AUX_OUT1];      set_property IOSTANDARD LVCMOS33 [get_ports AUX_OUT1]
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

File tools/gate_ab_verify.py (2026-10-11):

#!/usr/bin/env python3
"""Gate A/B netlist-backed electrical audit and deliberately bounded ngspice checks.

This is NOT vendor-device simulation, a certified shutdown-time bound, or a
fabrication approval. A passing execution means only the automated evidence ran.
Use a freshly exported KiCad XML netlist (never the tracked historical XML).
"""
from __future__ import annotations

import argparse
import hashlib
import itertools
import json
import math
from pathlib import Path
import re
import shutil
import subprocess
import sys
import xml.etree.ElementTree as ET


ADC_AVDD_MIN_V = 4.75                 # TI ADS8588S operating minimum
G33_THRESHOLD_V = 3.07               # TPS3808G33 nominal falling threshold
G33_THRESHOLD_TOL = 0.015
SUPERVISOR_HYSTERESIS_MAX = 0.025    # Conservative margin from project review
INA_GAIN_V_PER_V = 20.0              # INA240A1 nominal gain
MOSFET_VDS_MAX_V = 100.0             # BSC040N10NS5 absolute maximum
MOSFET_QG_MAX_C = 72e-9              # At published test conditions, not worst application
DRV8300_SOURCE_PEAK_A = .75           # Nominal/advertised peak, NOT guaranteed lower bound
DRV8300_SINK_PEAK_A = 1.5
PWM_HZ = 20_000
PHASE_RMS_A = 10.0


class TopologyError(ValueError):
    """A critical physical-pin / component-value requirement did not hold."""


def passive(value: str) -> float:
    """Accept project values (5mR, 47R, 160k, 1nF, 100uF)."""
    text = value.strip().replace("Ohm", "R").replace("Ω", "R")
    match = re.fullmatch(r"(\d+(?:\.\d+)?)([GMkmunp]?)([RF]?)", text)
    if not match:
        raise TopologyError(f"Unsupported passive value: {value!r}")
    prefix = match.group(2)
    factor = {"": 1.0, "G": 1e9, "M": 1e6, "k": 1e3,
              "m": 1e-3, "u": 1e-6, "n": 1e-9, "p": 1e-12}[prefix]
    return float(match.group(1)) * factor


def read_netlist(path: Path) -> tuple[dict[str, str], dict[tuple[str, str], str]]:
    root = ET.parse(path).getroot()
    if root.tag != "export":
        raise TopologyError("Expected KiCad XML <export> netlist")
    components = {c.attrib["ref"]: c.findtext("value", "")
                  for c in root.findall("./components/comp")}
    pins: dict[tuple[str, str], str] = {}
    for net in root.findall("./nets/net"):
        for node in net.findall("node"):
            key = (node.attrib["ref"], node.attrib["pin"])
            if key in pins:
                raise TopologyError(f"Duplicate physical pin in XML: {key}")
            pins[key] = net.attrib["name"]
    if len(components) < 150 or len(pins) < 300:
        raise TopologyError("Unexpectedly incomplete KiCad export: fail closed")
    return components, pins


def require_graph(components: dict[str, str],
                  pins: dict[tuple[str, str], str]) -> dict[str, float]:
    """A narrow independent physics-facing contract, not a replacement for ERC."""
    def value(ref: str, expected: str | float) -> float:
        if ref not in components:
            raise TopologyError(f"Required component missing: {ref}")
        raw = components[ref]
        if isinstance(expected, str):
            if raw != expected:
                raise TopologyError(f"{ref}: expected {expected}, got {raw}")
            return math.nan
        parsed = passive(raw)
        if not math.isclose(parsed, expected, rel_tol=1e-8, abs_tol=1e-15):
            raise TopologyError(f"{ref}: expected {expected}, got {raw}")
        return parsed

    def net(ref: str, pin: str | int) -> str:
        key = (ref, str(pin))
        if key not in pins:
            raise TopologyError(f"Pin {ref}.{pin} absent from exported XML")
        name = pins[key]
        if name.startswith("unconnected-"):
            raise TopologyError(f"Required pin disconnected: {ref}.{pin}")
        return name

    def rail(ref: str, pin: str | int, name: str) -> None:
        found = net(ref, pin)
        if found != "/" + name:
            raise TopologyError(f"{ref}.{pin} expected /{name}, got {found}")

    def same(*terminals: tuple[str, int | str]) -> None:
        names = [net(ref, pin) for ref, pin in terminals]
        if len(set(names)) != 1:
            raise TopologyError(f"Disconnected physical topology {terminals}: {names}")

    for ref in ("U2", "U3", "U4"):
        value(ref, "INA240A1DR")
    value("U1", "DRV8300DPWR")  # D non-inverted; DI is unsafe with the all-low inhibit.
    value("U6", "ADS8588SIPM")
    value("U15", "LM393LVDDFR")
    value("U5", "INA240A1DR")
    value("F1", "25A_0456025.ER")
    for obsolete in ("U16", "R51", "R52", "D2", "D3", "D4", "J2"):
        if obsolete in components:
            raise TopologyError(f"Obsolete phase OCP/bootstrap component present: {obsolete}")
    value("U24", "TPS3808G33")
    value("U25", "TPS389001DSER")
    value("U13", "TPS62901RPJR")
    for ref, expected in (("R92", 3240.), ("R93", 1000.),
                          ("R94", 75000.), ("R95", 10000.), ("C94", 100e-9)):
        value(ref, expected)

    for ref, expected in (("R50", 8200.), ("R53", 2000.),
                          ("R1", 280e3), ("R2", 280e3), ("R3", 39e3),
                          ("C5", 10e-9), ("C1", 100e-6), ("C2", 100e-6)):
        value(ref, expected)

    for phase, shunt, amp, filter_r, filter_c, adc_pin in (
        ("U", "RSH1", "U2", "R40", "C40", 49),
        ("V", "RSH2", "U3", "R41", "C41", 51),
        ("W", "RSH3", "U4", "R42", "C42", 53),
    ):
        value(shunt, 0.005)
        value(filter_r, 47)
        value(filter_c, 1e-9)
        same((shunt, 1), (amp, 8))
        same((shunt, 2), (amp, 1))
        rail(shunt, 1, f"SW_{phase}")
        rail(shunt, 2, f"PH_{phase}")
        rail(amp, 2, "GND")           # GND
        rail(amp, 3, "GND")           # REF2
        rail(amp, 4, "GND")           # NC: INA240 D permits GND or floating; design grounds it
        rail(amp, 6, "VA_5V")        # VS
        rail(amp, 7, "VA_5V")        # REF1; 0.5 * supply centering
        same((amp, 5), (filter_r, 1))
        same((filter_r, 2), (filter_c, 1), ("U6", adc_pin))
        phase_nets = {net(amp, 5), net(filter_r, 2)}
        if any(name in phase_nets for (ref, _), name in pins.items() if ref in ("U15", "U16")):
            raise TopologyError(f"Phase {phase} OCP tap resurrected")
        rail(filter_c, 2, "GND")

    value("RSH4", .002)
    rail("RSH4", 1, "VBUS_PROT")
    rail("RSH4", 2, "VBUS_BRIDGE")
    same(("U5", 8), ("RSH4", 1))
    same(("U5", 1), ("RSH4", 2))
    for pin in (2, 3, 4, 7):
        rail("U5", pin, "GND")
    rail("U5", 6, "VA_5V")
    same(("U5", 5), ("U15", 2))  # Positive bus current pulls OCP_N low.
    # Native Infineon PG-TDSON footprint numbers all drain lands 5;
    # there are no separate schematic pins 6..8. PCB parity checks every land.
    for ref in ("Q1", "Q3", "Q5"):
        rail(ref, 5, "VBUS_BRIDGE")
    rail("R50", 1, "VA_5V")
    rail("R53", 2, "GND")
    same(("R50", 2), ("R53", 1), ("U15", 3), ("U15", 6))
    for pin in (4, 5):
        rail("U15", pin, "GND")
    rail("U15", 8, "VA_5V")
    rail("U15", 1, "OCP_N")
    if not pins.get(("U15", "7"), "").startswith("unconnected-"):
        raise TopologyError("Unused U15.7 output must remain NC")
    for cap, ic, power, ground in (("C84", "U5", 6, 2), ("C85", "U15", 8, 4)):
        value(cap, 100e-9)
        same((cap, 1), (ic, power))
        same((cap, 2), (ic, ground))
    same(("J3", 1), ("F1", 1))
    same(("F1", 2), ("Q7", 5), ("U18", 1), ("U18", 5))
    if net("F1", 1).rsplit("/", 1)[-1] != "VIN_RAW" or net("F1", 2).rsplit("/", 1)[-1] != "VIN_FUSED":
        raise TopologyError("Onboard F1 must separate VIN_RAW from VIN_FUSED")
    if "J6" in components:  # System XML retains the off-board source interface.
        same(("J6", 1), ("J3", 1))

    for pin in list(range(16, 23)) + list(range(27, 34)):
        rail("U6", pin, "GND")  # TI serial-mode straps
    for pin in (1, 37, 38, 48):
        rail("U6", pin, "VA_5V")
    rail("U6", 6, "VIO_3V3")

    rail("U1", 7, "VDRV_12V")
    rail("U1", 8, "GND")
    for phase, cap, bst_pin, vs_pin in (
        ("U", "CBOOT1", 20, 18), ("V", "CBOOT2", 17, 15),
        ("W", "CBOOT3", 14, 12),
    ):
        value(cap, 470e-9)
        same((cap, 1), ("U1", bst_pin))
        rail(cap, 2, f"SW_{phase}")
        rail("U1", vs_pin, f"SW_{phase}")
    for index, output in enumerate((19, 11, 16, 10, 13, 9), 1):
        value(f"RG{index}", 33.)
        same(("U1", output), (f"RG{index}", 1))
        same((f"RG{index}", 2), (f"Q{index}", 4))
    for gate, output, driver in (("U8", 7, 1), ("U9", 7, 2), ("U10", 7, 3),
                                  ("U8", 3, 4), ("U9", 3, 5), ("U10", 3, 6)):
        same((gate, output), ("U1", driver))

    rail("U24", 5, "VIO_3V3")
    same(("U25", 1), ("R92", 2), ("R93", 1))
    rail("R92", 1, "VA_5V")
    rail("R93", 2, "GND")
    rail("U25", 2, "GND")
    rail("U25", 3, "VIO_3V3")
    same(("U25", 5), ("C94", 1))
    rail("C94", 2, "GND")
    rail("U24", 6, "VIO_3V3")
    rail("U25", 4, "VIO_3V3")
    same(("U24", 1), ("U25", 6), ("U26", 1))
    same(("U26", 3), ("U15", 1))
    same(("U26", 2), ("U11", 3))
    same(("U20", 5), ("U11", 6))
    rail("U11", 1, "GATE_EN")

    # All values below originate from the current XML, not historical reports.
    result = {ref: passive(components[ref]) for ref in (
        "R1", "R2", "R3", "C5", "C1", "C2", "R50", "R53", "R40", "C40", "RSH1", "RSH2", "RSH3", "RSH4"
    )}
    return result


def corner_current_limits(values: dict[str, float],
                          rail_range: tuple[float, float] = (4.75, 5.25),
                          resistor_fraction: float = 0.001,
                          shunt_fraction: float = 0.01,
                          nominal_rail: float = 5.1) -> dict:
    """Positive bus-only passive corners; caller supplies actual regulated rail bounds."""
    trips = []
    for rail, top, bottom, shunt in itertools.product(
        rail_range,
        (values["R50"] * (1-resistor_fraction), values["R50"] * (1+resistor_fraction)),
        (values["R53"] * (1-resistor_fraction), values["R53"] * (1+resistor_fraction)),
        (values["RSH4"] * (1-shunt_fraction), values["RSH4"] * (1+shunt_fraction)),
    ):
        trips.append(rail * bottom / (top + bottom) / (INA_GAIN_V_PER_V * shunt))
    threshold = nominal_rail * values["R53"] / (values["R50"] + values["R53"])
    return {
        "reference_nominal_V": threshold,
        "positive_trip_nominal_A": threshold / (INA_GAIN_V_PER_V * values["RSH4"]),
        "positive_passive_corner_A": [min(trips), max(trips)],
        "reverse_current_protection": False,
        "rail_range_V": list(rail_range),
        "corner_basis": "Supplied VA5 bounds; R50/R53 +/-0.1%; RSH4 +/-1%; both INA references grounded",
        "excluded": ["INA240 gain/offset/output swing and PWM common-mode recovery",
                     "LM393LV offset, propagation, overdrive and open-drain pull-up",
                     "Temperature drift/assembly thermal, layout parasitics",
                     "Fault current slope and complete MOSFET turn-off timing"],
    }



def bus_static_error_budget(values: dict[str, float], rail_range: tuple[float, float]) -> dict:
    """Conditional engineering budget for selected BOM, not guaranteed protection.

    INA240 SBOS662C p5; LM393LV SNOSDA4D p10; RESI PTFR C16003 V8
    ordering code P; FH TD code G; HoYLR HoS20260514-73 pp3/5.
    Shunt TCR is specified only +25..+125C, hence no cold-range claim.
    """
    resistor_fraction = .001 + 25e-6 * 105  # worst difference from +20C reference
    shunt_fraction = .01 + 50e-6 * 100
    gain_fraction = .002 + 2.5e-6 * 100
    rail_deviation = max(abs(rail - 5.) for rail in rail_range)
    # INA: VOS + temperature + DC common-mode change 12V -> 48V + PSRR.
    ina_offset = 25e-6 + 250e-9 * 100 + 36 * 10**(-120/20) + 10e-6 * rail_deviation
    # Comparator full-temperature VOS already includes drift; add CMRR and PSRR.
    # 1.1V bounds both comparator input voltages around the 1V crossing.
    comparator_offset = .003 + 1.1 * 10**(-60/20) + rail_deviation * 10**(-70/20)
    trips = []
    for rail, top, bottom, shunt, gain, ina_vos, comp_vos in itertools.product(
        rail_range,
        (values["R50"]*(1-resistor_fraction), values["R50"]*(1+resistor_fraction)),
        (values["R53"]*(1-resistor_fraction), values["R53"]*(1+resistor_fraction)),
        (values["RSH4"]*(1-shunt_fraction), values["RSH4"]*(1+shunt_fraction)),
        (20*(1-gain_fraction), 20*(1+gain_fraction)),
        (-ina_offset, ina_offset), (-comparator_offset, comparator_offset),
    ):
        trips.append(((rail*bottom/(top+bottom)+comp_vos)/gain-ina_vos)/shunt)
    return {
        "nominal_trip_A": 25,
        "positive_static_engineering_corner_A": [min(trips), max(trips)],
        "guaranteed_trip_interval": False,
        "component_temperature_scope_C": [25, 125],
        "temperature_scope_note": "Calculation envelope only; board target and each component's lower temperature limit still apply. Cold shunt TCR not qualified.",
        "bus_common_mode_scope_V": [24, 48],
        "fractions": {"R50_R53_initial_plus_TCR": resistor_fraction,
                      "RSH4_initial_plus_TCR": shunt_fraction,
                      "INA_gain_initial_plus_drift": gain_fraction},
        "INA_input_offset_total_V": ina_offset,
        "LM393_input_offset_total_V": comparator_offset,
        "oem_sources": [
            {"url": "https://www.ti.com/lit/ds/symlink/ina240.pdf", "document": "SBOS662C", "section": "7.5, page5: gain/offset/drift, CMRR, PSRR and reference rejection"},
            {"url": "https://www.ti.com/lit/ds/symlink/lm393lv.pdf", "document": "SNOSDA4D", "section": "5.9, page10: LM393LV offset, CMRR, PSRR and table conditions"},
            {"url": "https://atta.szlcsc.com/upload/public/pdf/source/20250401/FF0B2EF5B31106388F28E532ECCD4B84.pdf", "document": "RESI PTFR C16003 V8", "section": "printedpage2 orderingcode P=25ppm/C; printedpage3 TCR reference20C"},
            {"url": "https://atta.szlcsc.com/upload/public/pdf/source/20200616/C657321_2CFA27FA726BC0D0F6223AF922169515.pdf", "document": "FH TD thin-film specification", "section": "orderingcode G=25ppm/C"},
            {"url": "https://atta.szlcsc.com/upload/public/pdf/source/20260807/2744A3B9486B05923CE3C700940B3DAC.pdf", "document": "HoS20260514-73 A0, HoYLR2512-3W-2mR-1%", "section": "page3 TCR50ppm/C; page5 test temperature25..125C and separate reliability allowances"}],
        "selected_parts": {"R50": "PTFR0603B8K20P9", "R53": "TD03G2001BT",
                           "RSH4": "HoYLR2512-3W-2mR-1%"},
        "limits": ["Not a guaranteed interval: LM393 offset/CMRR/PSRR table conditions are at/up to 5V; applying at actual 5.026..5.174V needs validation.",
                   "INA reference rejection and bias-current mismatch lack guaranteed maxima; grounded-reference application needs validation.",
                   "No assembly/reflow, long-term/load-life/humidity drift, thermoelectric or Kelvin copper error allocation.",
                   "No PWM common-mode transient, ripple, propagation delay, fault slope or MOSFET turn-off model."]}


def require_bus_budget_parts(netlist: Path) -> None:
    root = ET.parse(netlist).getroot()
    expected = {"R50": "PTFR0603B8K20P9", "R53": "TD03G2001BT",
                "RSH4": "HoYLR2512-3W-2mR-1%"}
    for ref, mpn in expected.items():
        comp = root.find(f'./components/comp[@ref="{ref}"]')
        actual = comp.findtext('./fields/field[@name="MPN"]') if comp is not None else None
        if actual != mpn:
            raise TopologyError(f"{ref}: static thermal budget requires reviewed MPN {mpn}; got {actual}")


def gate_report(netlist: Path) -> dict:
    components, pins = read_netlist(netlist)
    v = require_graph(components, pins)
    require_bus_budget_parts(netlist)
    cap = v["C1"] + v["C2"]
    shunt_powers = [PHASE_RMS_A**2 * v[ref] for ref in ("RSH1", "RSH2", "RSH3")]
    tau = v["R40"] * v["C40"]
    from check_adc_validity import verify as verify_adc
    adc_errors, adc_numerics = verify_adc(netlist)
    if adc_errors:
        raise TopologyError("; ".join(adc_errors))
    g33_release_max = G33_THRESHOLD_V * (1+G33_THRESHOLD_TOL) * (1+SUPERVISOR_HYSTERESIS_MAX)
    return {
        "schema_version": 2,
        "erc": {"status": "NOT_RUN", "reason": "Netlist checks do not execute ERC; use run_gate_ab.py"},
        "scope": "Electrical source checks + nominal/illustrative passive models only",
        "source_netlist_sha256": hashlib.sha256(netlist.read_bytes()).hexdigest(),
        "observed_system_components": len(components),
        "graph_checks": "PASS: pin-mapped current, ADC, bootstrap, OCP comparator/supervisor",
        "target": {"vbus_min_V": 24, "vbus_max_V": 48,
                   "phase_continuous_rms_provisional_A": PHASE_RMS_A, "pwm_Hz": PWM_HZ},
        "numerics": {
            "current_gain_V_per_A": INA_GAIN_V_PER_V * v["RSH1"],
            "shunt_loss_each_W_at_10A_RMS": shunt_powers,
            "bus_divider_48V_output_V": 48*v["R3"]/(v["R1"]+v["R2"]+v["R3"]),
            "bus_monitor_tau_s": ((v["R1"]+v["R2"])*v["R3"]/
                                   (v["R1"]+v["R2"]+v["R3"]))*v["C5"],
            "current_rc_tau_s": tau,
            "current_rc_fc_Hz": 1/(2*math.pi*tau),
            "six_mosfet_gate_charge_ideal_energy_rate_W_not_device_power": (
                6*MOSFET_QG_MAX_C*12*PWM_HZ),
            "illustrative_qg_div_peak_source_s_NOT_a_bound": MOSFET_QG_MAX_C/DRV8300_SOURCE_PEAK_A,
            "illustrative_qg_div_peak_sink_s_NOT_a_bound": MOSFET_QG_MAX_C/DRV8300_SINK_PEAK_A,
            "regeneration": {
                "bulk_nominal_F": cap,
                "energy_48_to_55_J": 0.5*cap*(55**2-48**2),
                "ideal_no_sink_1A_time_48_to_55_s": (55-48)*cap,
                "illustrative_1A_no_sink_after_1ms_V": 48 + 0.001/cap,
                "warning": "55V is NOT an approved voltage; ignores source/load and parasitics",
            },
            "adc_supply_vs_supervisor": {
                "ADS8588S_AVDD_min_V": ADC_AVDD_MIN_V,
                "G33_worst_recovery_threshold_V": g33_release_max,
                **adc_numerics,
                "conclusion": "Static threshold gap repaired; rapid droop/full-chain shutdown timing remains unqualified",
            },
            "bus_ocp_static_budget": bus_static_error_budget(v, tuple(adc_numerics["regulated_static_V"])),
            "ocp": corner_current_limits(v, rail_range=tuple(adc_numerics["regulated_static_V"]), nominal_rail=.6*(1+passive(components['R94'])/passive(components['R95']))),
        },
        "gate_a": {
            "status": "BLOCKED",
            "passed_checks": ["physical netlist contract", "ADC static threshold/recovery corners"],
            "blocking_ids": ["A-ADC-UNDERVOLTAGE", "A-PEAK-THERMAL-SPEC",
                             "A-VENDOR-FOOTPRINT-MPN", "A-POWER-SEQUENCING"],
        },
        "gate_b": {
            "status": "BLOCKED",
            "blocking_ids": ["B-IC-TRANSIENT-MODELS", "B-TOTAL-OCP-DELAY",
                             "B-REGENERATION-SINK", "B-SWITCHING-SOA",
                             "B-BENCH-EVIDENCE"],
        },
        "interpretation": (
            "PASS of graph and SPICE checks is not Gate A/B closure, STO, "
            "PCB fabrication release or qualification of any active device"
        ),
    }


def generate_spice(values: dict[str, float], output_dir: Path) -> dict[str, Path]:
    """Explicit ideal-source/passive decks; no hidden vendor-model claim."""
    output_dir.mkdir(parents=True, exist_ok=True)
    cap = values["C1"] + values["C2"]
    regen = output_dir / "regeneration.cir"
    regen.write_text(f"""* Ideal unsunk DC-link regeneration. Not a clamp qualification.
Iregen 0 bus DC 1
Cbulk bus 0 {cap:.12g} IC=48
.tran 1u 1.4m uic
.control
set wr_singlescale
set wr_vecnames
run
wrdata regeneration.dat v(bus)
quit
.endc
.end
""", encoding="utf-8")
    filter_deck = output_dir / "phase_current_filter.cir"
    filter_deck.write_text(f"""* Ideal voltage step representing a current-amplifier output.
* No INA, comparator, latch, driver or MOSFET models present.
Vmeas source 0 PWL(0 2.5 1u 2.5 1.001u 4.9 1.4u 4.9)
R40 source filtered {values['R40']:.12g}
C40 filtered 0 {values['C40']:.12g} IC=2.5
.tran 1n 1.35u uic
.control
set wr_singlescale
set wr_vecnames
run
wrdata phase_current_filter.dat v(filtered)
quit
.endc
.end
""", encoding="utf-8")
    return {"regeneration": regen, "phase_current_filter": filter_deck}


def _rows(path: Path) -> list[tuple[float, float]]:
    result = []
    for index, line in enumerate(path.read_text(encoding="utf-8").splitlines()):
        cols = line.split()
        if not cols:
            continue
        if not result and index == 0 and cols[0].lower() == "time":
            continue
        if len(cols) != 2:
            raise RuntimeError(f"Malformed waveform row: {path}:{index+1}")
        try:
            t, value = map(float, cols)
        except ValueError as exc:
            raise RuntimeError(f"Malformed waveform row: {path}:{index+1}") from exc
        if not (math.isfinite(t) and math.isfinite(value)) or t < 0:
            raise RuntimeError(f"Nonfinite/negative waveform data: {path}:{index+1}")
        if result and t <= result[-1][0]:
            raise RuntimeError(f"Nonmonotonic waveform time: {path}:{index+1}")
        result.append((t, value))
    if len(result) < 2:
        raise RuntimeError(f"Incomplete ngspice waveform: {path}")
    return result
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

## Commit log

2026-09-29 chore: initialize fpga-servo repository
2026-09-29 feat: add AX7010 servo drive Rev.A hardware baseline
    [ax7010_servo_reva.kicad_pcb, ax7010_servo_reva.sch, bom.csv]
2026-09-29 fix: align BOM references with Rev.A EDA baseline
    [bom.csv]
2026-09-29 fix(kicad): add legacy schematic cache library
2026-09-29 feat(schematic): refactor Rev.A into functional hierarchy
    [aux_power.sch, ax7010_interface.sch, ax7010_servo_reva.sch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]
2026-09-29 fix(schematic): close input protection and PWM safety paths
    [ax7010_servo_reva.sch, gate_inverter.sch, power_input.sch]
2026-09-29 feat(power): implement reference-derived rails and ADC/OCP sheet
    [aux_power.sch, current_adc.sch]
2026-09-29 fix(schematic): close power, ADC, gate and encoder electrical nets
    [aux_power.sch, current_adc.sch, encoder.sch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]
2026-09-29 fix(kicad): use valid legacy hierarchical-label types
    [aux_power.sch, ax7010_interface.sch, current_adc.sch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]
2026-09-29 test(kicad): validate hierarchical legacy schematic syntax
2026-09-29 fix(kicad): normalize legacy timestamps and strip blank lines
    [current_adc.sch, encoder.sch, gate_inverter.sch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]
2026-09-29 test(kicad): reject blank legacy lines and bad timestamps
2026-09-29 fix(ci): distinguish sheet UUIDs from component timestamps
    [check_design.py]
2026-09-29 test(kicad): add legacy schematic parser smoke check
2026-09-29 feat(kicad): wire DC input and protection sheet
    [power_input.sch]
2026-09-29 feat(kicad): wire auxiliary power rails
    [aux_power.sch]
2026-09-29 feat(kicad): wire PWM safety and three-phase inverter
    [gate_inverter.sch]
2026-09-29 feat(kicad): wire current sensing OCP and ADC sheet
    [current_adc.sch]
2026-09-29 feat(kicad): wire differential ABZ encoder sheet
    [encoder.sch]
2026-09-29 feat(kicad): wire AX7010 PL interface headers
    [ax7010_interface.sch]
2026-09-29 feat(kicad): close top-level hierarchical wiring
    [ax7010_servo_reva.sch]
2026-09-29 test(kicad): validate pin wiring and hierarchy interfaces
2026-09-29 refactor(kicad): compact power and encoder sheets to A4
    [aux_power.sch, encoder.sch, power_input.sch]
2026-09-29 refactor(kicad): compact inverter ADC and PL interface sheets to A4
    [ax7010_interface.sch, current_adc.sch, gate_inverter.sch]
2026-09-29 fix(kicad): improve A4 spacing for inverter and ADC sheets
    [current_adc.sch, gate_inverter.sch]
2026-09-29 refactor(kicad): compact top-level hierarchy to A4
    [ax7010_servo_reva.sch]
2026-09-29 fix(kicad): remove blank legacy lines from gate_inverter.sch
    [gate_inverter.sch]
2026-09-29 fix(kicad): remove blank legacy lines from current_adc.sch
    [current_adc.sch]
2026-09-29 test(kicad): enforce A4 schematic page standard
2026-09-29 refactor(kicad): make inverter power chains visually continuous
    [gate_inverter.sch]
2026-09-29 refactor(kicad): clean current ADC and hardware OCP presentation
    [current_adc.sch]
2026-09-29 refactor(kicad): group AX7010 interface by real-time function
    [ax7010_interface.sch]
2026-09-29 ci(kicad): run native ERC on schematic hierarchy
2026-09-29 fix(ci): run native ERC with KiCad 10
2026-09-29 fix(kicad): separate gate-source pull-downs from MOSFET bodies
    [gate_inverter.sch]
2026-09-29 fix(kicad): normalize symbol pins to 50mil grid
2026-09-29 fix(kicad): regrid power_input.sch connections
    [power_input.sch]
2026-09-29 fix(kicad): regrid aux_power.sch connections
    [aux_power.sch]
2026-09-29 fix(kicad): regrid encoder.sch connections
    [encoder.sch]
2026-09-29 fix(kicad): regrid inverter visual chains to 50mil
    [gate_inverter.sch]
2026-09-29 fix(kicad): regrid ADC OCP wiring to 50mil
    [current_adc.sch]
2026-09-29 fix(kicad): regrid AX7010 header connections to 50mil
    [ax7010_interface.sch]
2026-09-29 fix(kicad): align auxiliary power parts to 50mil grid
    [aux_power.sch]
2026-09-29 fix(kicad): snap all electrical coordinates to 50mil grid
    [aux_power.sch, ax7010_interface.sch, ax7010_servo_reva.sch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]
2026-09-29 fix(kicad): restore and regrid ax7010_servo_reva.sch
    [ax7010_servo_reva.sch]
2026-09-29 fix(kicad): restore and regrid power_input.sch
    [power_input.sch]
2026-09-29 fix(kicad): restore and regrid aux_power.sch
    [aux_power.sch]
2026-09-29 fix(kicad): restore and regrid gate_inverter.sch
    [gate_inverter.sch]
2026-09-29 fix(kicad): restore and regrid current_adc.sch
    [current_adc.sch]
2026-09-29 fix(kicad): restore and regrid encoder.sch
    [encoder.sch]
2026-09-29 fix(kicad): restore and regrid ax7010_interface.sch
    [ax7010_interface.sch]
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2026-09-29 fix(ci): run ERC from KiCad project directory
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2026-09-29 fix(schematic): compact Rev.A1 layout and repair net drafting
    [aux_power.sch, ax7010_interface.sch, current_adc.sch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]
2026-09-29 fix(schematic): instantiate child symbols in hierarchy
    [aux_power.sch, ax7010_interface.sch, current_adc.sch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]
2026-09-30 fix(schematic): repair Rev.A net connectivity and sheet layout
    [aux_power.sch, ax7010_interface.sch, ax7010_servo_reva.sch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]
2026-09-30 调整原理图字体位置
    [aux_power.sch, ax7010_interface.sch, current_adc.sch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]
2026-09-30 fix: optimize KiCad schematic wiring and close ERC (#2)
    Close the Rev.A1 schematic cleanup by enforcing hierarchical wiring/layout rules, restoring KiCad 10 conversion/ERC correctness, replacing invalid footprint links, and recording acceptance evidence.
    Validated on head 77e2d38 with hardware-sanity #187, KiCad 10 netlist export (124 components / 163 nets), ERC 0 errors / 0 warnings, connectivity checks, and layout checks.
    [aux_power.sch, ax7010_interface.sch, current_adc.sch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]
2026-09-30 chore: migrate schematic source to native KiCad 10 (#3)
    Make the KiCad 10-native schematic hierarchy and native project symbol library authoritative. Remove legacy .sch/.lib sources and tracked local library-table state, migrate repository checks to native files, and run ERC directly on the tracked native hierarchy.
    Validated on head 761f775 with hardware-sanity #227 and kicad-erc #66: 124 components / 163 nets, ERC 0 errors / 0 warnings.
    [aux_power.kicad_sch, aux_power.sch, ax7010_interface.kicad_sch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]
2026-09-30 fix: draw power input as continuous functional wiring
    [power_input.kicad_sch]
2026-10-09 fix(schematic): add supervised OCP latch and verify safety paths
    [aux_power.kicad_sch, ax7010_interface.kicad_sch, ax7010_servo_reva.kicad_sch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]
2026-10-09 chore(agents): add project KiCad repair skill and branch rules
2026-10-09 fix(pcb): correct M3 mounting hole drills and record sync audit
    Increase H1-H4 drills from 1.0 mm to 3.2 mm while preserving hole centers, pad size, board outline and copper. Add an undersized M3-hole regression check and document the refreshed physical-pin PCB audit and release gates.
    Validation: five repository checks, fresh 158-component/183-net safety check and 531 OCP digital scenarios pass. ERC remains 0 errors/0 warnings. Latest PCB DRC remains 357 violations and 129 unconnected items; layout freeze is still blocked.
    [ax7010_servo_reva.kicad_pcb]
2026-10-09 fix(pcb): restore native parity and replace power footprints
    Synchronize 158 electrical components and four mechanical footprints with
    physical pad nets, schematic paths, DNP states and native package geometry.
    Preserve the outline, mounting centers and all 20 legacy track geometries.
    Replace power terminals with Phoenix Contact 1714971/1714984 and shunts
    with Ohmite 650FPR005E using project-local footprints and package evidence.
    Ground INA241 U2/U3/U4 reserved pin 4 per TI SBOSA30D; the fresh netlist is
    158 components / 180 nets. Update BOM, placement and netclass assignments.
    Add physical-pad/DNP parity and mechanical/netclass checks to CI, with
    11 behavioral regressions. Record remainin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
    [ax7010_servo_reva.kicad_pcb, bom.csv, current_adc.kicad_sch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]
2026-10-09 chore(kicad): install PCB review skills and local QA tools
    Deploy four project-local skills and preserve source provenance. Adapt the
    Windows QA entry point to KiCad 10.0.3 and existing safety checks.
    Fix KiCad 10 embedded-net parsing and hierarchy slash normalization.
    Validation: four tutorial regressions and four skill format checks pass.
    Native end-to-end QA retains real PCB DRC failures; no release claim.
2026-10-09 fix(schematic): select external fuse and confirm AX7010 J10 interface
    Select KLKD025.T with LPSM0001Z holder at the source. Model external PSU
    terminal J6 and F1 off-board, with J3.1 connected to VIN_FUSED. Remove
    the unqualified 2920 fuse footprint and distinguish external BOM objects.
    Record the user-confirmed AX7010 2022 / J10 baseline without pin changes.
    Add fuse/source and active J10 pin regressions; update release evidence.
    Validation: five repository checks, safety graph, 531 OCP scenarios,
    11 PCB checker regressions, and four tutorial regressions pass.
    Fresh ERC: 0 errors / 0 warnings / 0 exclusions. System BOM: 159 objects;
    PCB netlist: 157 board components / 179 nets.
    PCB unchan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
    [ax7010_interface.kicad_sch, bom.csv, power_input.kicad_sch]
2026-10-09 fix(schematic): humanize full hierarchy and preserve page navigation
    [aux_power.kicad_sch, ax7010_interface.kicad_sch, ax7010_servo_reva.kicad_sch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]
2026-10-09 fix(schematic): connect local power and ground graphics
    [aux_power.kicad_sch, ax7010_interface.kicad_sch, ax7010_servo_reva.kicad_sch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]
2026-10-09 fix(kicad): correct diode polarity and serial ADC grounding
    [ax7010_servo_reva.kicad_pcb, before.kicad_pcb, bus_divider.csv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]
2026-10-09 ci(verification): capture KiCad and ngspice Gate A/B artifacts without false sign-off
2026-10-09 fix(verification): label Qg/driver-peak calculations as illustrative, never timing bounds
    [gate_ab_verify.py]
2026-10-09 fix(verification): bind Gate A/B checks to fresh native evidence
    [gate_ab_verify.py, run_gate_ab.py, test_gate_ab_verify.py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]
2026-10-10 docs(audit): record schematic layout entry blockers
    [schematic_layout_entry_audit_2026-10-10_findings.csv]
2026-10-10 fix(schematic): inhibit PWM on ADC supply undervoltage
    [aux_power.kicad_sch, ax7010_servo_reva.kicad_pcb, bom.csv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]
2026-10-10 fix(pcb): adopt reviewed copper repair development baseline
    Rebuild all 20 legacy copper paths and six independent shunt Kelvin routes;
    correct the ground-plane net and adjust half-bridge/terminal placement.
    Adopt the reviewed PCB with explicit user approval as a development baseline.
    Preserve board outline, mounting holes, keepouts and original path UUIDs.
    Correct J2 assembly and supply annotations, external-component parity audit,
    CLEAR guidance and operating inputs (10Arms, 20A/30s, 40C, 50K, forced air).
    Remove brake implementation from scope per the latest user instruction.
    Archive migration, adoption hashes and native verification evidence.
    Validation: six project checks, safety/OCP,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
    [aux_power.kicad_sch, ax7010_interface.kicad_sch, ax7010_servo_reva.kicad_pcb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]
2026-10-10 fix(pcb): checkpoint routing rules, vendor lands and Kelvin isolation
    Add manufacturer land patterns and bounded internal-pad clearance rules.
    Preserve current two-layer routing and control/ADC ground copper.
    Model four-terminal shunt internal pairs and verify isolated Kelvin branches.
    Update schematic footprint assignments, BOM, checks and review evidence.
    Validation: six project checks, 21 regression tests, physical PCB parity,
    safety netlist checks and 531 OCP stable-level scenarios pass. Native ERC
    has 0 violations; native DRC has 0 violations, 64 unconnected, 0 parity
    issues. Six Kelvin branches pass. Routing closure and fabrication release
    remain open; existing ignored check categorie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
    [ax7010_servo_reva.kicad_pcb, bom.csv, current_adc.kicad_sch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]
2026-10-10 fix(pcb): complete routing and bevel VBUS corners
    [ax7010_servo_reva.kicad_pcb]
2026-10-10 fix(pcb): bevel trace corners and audit copper connectivity
    [ax7010_servo_reva.kicad_pcb]
2026-10-10 refactor(schematic): in-stock INA240A1 and open-drain LM339LV; block legacy shunt manufacturing
    [ax7010_servo_reva.kicad_pcb, bom.csv, current_adc.kicad_sch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]
2026-10-10 feat(schematic): optimize LCSC sourcing and positive bus OCP
    [aux_power.kicad_sch, ax7010_interface.kicad_sch, ax7010_servo_reva.kicad_sch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]
2026-10-11 docs(bom): snapshot 68 procurement groups with cost, ECO and DFM review
    [reva_cost_eco_2026-10-11.csv]
2026-10-11 docs: replace obsolete FD6288/INA241 and DRC claims with current prototype baseline
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2026-10-11 fix(bom): make 68-group ECO cost CSV directly importable
    [reva_cost_eco_2026-10-11.csv]
2026-10-11 docs(hw): add source-backed in-stock 68uH alternatives and a bounded LM5164 current estimate
2026-10-12 fix(schematic): name NTC2 as board sensor and clarify dual-DOUT ADC
2026-10-12 fix(schematic): correct C3 film rating metadata to selected 250V part
2026-10-12 fix(schematic): remove misleading stale Coilcraft descriptor on L1
2026-10-12 fix(bom): align C3 250V, L1 qualification and NTC2 board sensor
2026-10-12 fix(schematic): correct NTC2 component description to onboard auxiliary sensor
2026-10-12 fix(fpga): disable unfitted J11/PL_B ADC-parallel placeholder constraints
2026-10-12 docs(fpga): freeze ADS8588S dual-serial timing, ADC latency and AX7010 actual J10 contract
2026-10-12 test(fpga): add six positive and fault-mutation ADC serial source regressions
2026-10-12 docs(fpga): align J10/J11 fitted status and two-lane ADC readout contract
2026-10-12 docs(hw): record actual schematic annotation fixes and open release gates
2026-10-12 docs: link corrected dual-DOUT ADC timing and component freeze status
2026-10-12 docs(hw): record schematic/MPN freeze blockers, verified sourcing candidates and Rev.A verification gates
2026-10-12 docs(hw): reconcile initial design review with subsequent actual schematic metadata ECO
2026-10-12 ci(hw): run fresh native ERC before known-blocked PCB parity without waiving PCB gate
2026-10-12 docs(power): incorporate LM5164 min-peak-limit margin and qualified 120uH option gates
2026-10-12 docs(hw): record native ERC zero and explicit failed PCB/manufacturing qualification evidence
2026-10-12 docs(hw): select AD7606C-16 four-lane low-latency ADC for high-bandwidth FPGA FOC ECO
2026-10-12 docs(bom): compare manufacturable fast ADC MPNs, current stocks and quote currencies
2026-10-12 spec(fpga): version AD7606C four-DOUT J10 pin allocation and register configuration
2026-10-12 docs(hw): correct AD7606C current-sense headroom wording and offset budget
2026-10-12 ci(hw): validate candidate high-bandwidth ADC profile without claiming hardware migration
2026-10-12 docs(hw): record candidate contract passes and honest legacy ERC/PCB gate results
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2026-10-17 fix(ci): separate schematic delivery from blocked PCB release gates
2026-10-17 docs: specify reusable PCB toolkit and documentation cleanup
2026-10-17 docs: plan reusable PCB toolkit migration and verification
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2026-10-17 refactor(tools): separate generic board checks from project rules
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2026-10-17 refactor(tools): complete shared PCB workflows and documentation migration
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2026-10-18 fix(hardware): design AD7606C auxiliary rail for total 1 A
    Update inductor, precision feedback and ripple components with a qualified land pattern and bounded static calculations. Preserve named-net and physical-pin parity. Repair native GUI save stability with explicit original-default wire widths and visible junctions; keep unrouted DRC and physical qualification gates blocked.
2026-10-18 fix(pcb): enforce actual AD7606C net classes and power layout gates
2026-10-18 feat(pcb): complete AD7606C routing and native CAD acceptance
2026-10-18 fix(hardware): repair dual servo prototype designs and release checks
2026-10-18 docs(hardware): record final CAD and CAM review packages
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2026-10-19 docs(audit): establish staged dual-servo review and recoverable source baseline
2026-10-19 fix(audit): stage AD7606C timing ECO with exact-byte native verification
2026-10-19 fix(hardware): apply verified stage-1-ad7606c-timing
2026-10-19 fix(hardware): publish stage-2 reviewed PCB ECO and native verification inputs
2026-10-19 fix(audit): distinguish native pad ordering from physical PCB changes
2026-10-19 test(pcb): target copper pad identity in native-order fault injection
2026-10-19 fix(pcb): keep U13 ground escape clear of widened supply land
2026-10-19 fix(hardware): apply verified stage-2-native-via-u13-land-and-return-frame
2026-10-19 docs(hardware): complete electrical thermal audit and record verified dual PCB closure
2026-10-19 feat(manufacturing): export frozen dual-board review packets with independent CAM checks
2026-10-19 fix(manufacturing): compare drill holes across native decimal quantization
2026-10-20 fix(hardware): externalize AD7606C DC-link and verify fabrication candidate
    Remove the onboard capacitor/damping bank, retain J7 for an external capacitor and bleeder, and synchronize PCB, BOM and interface documentation.
    Repair manufacturing snapshot/CAM portability, add regression coverage and retain source-bound review evidence. ERC/DRC/parity are clean; supplier acceptance and physical qualification remain open.
2026-10-20 fix(hardware): strengthen PWM safety gating on both ADC boards
    Retain independent latched shutdown, rename the gating block and adopt 10k driver-input pulldowns with synchronized BOM and PCB fields.
    Correct the digital model DCU8 channel mapping, reject obsolete substitutes, and retain native ERC/DRC, geometry and review evidence. RTL restart sequencing and physical qualification remain open.
2026-10-23 fix(schematic): align gate driver symbols with DRV8300 and record audit
